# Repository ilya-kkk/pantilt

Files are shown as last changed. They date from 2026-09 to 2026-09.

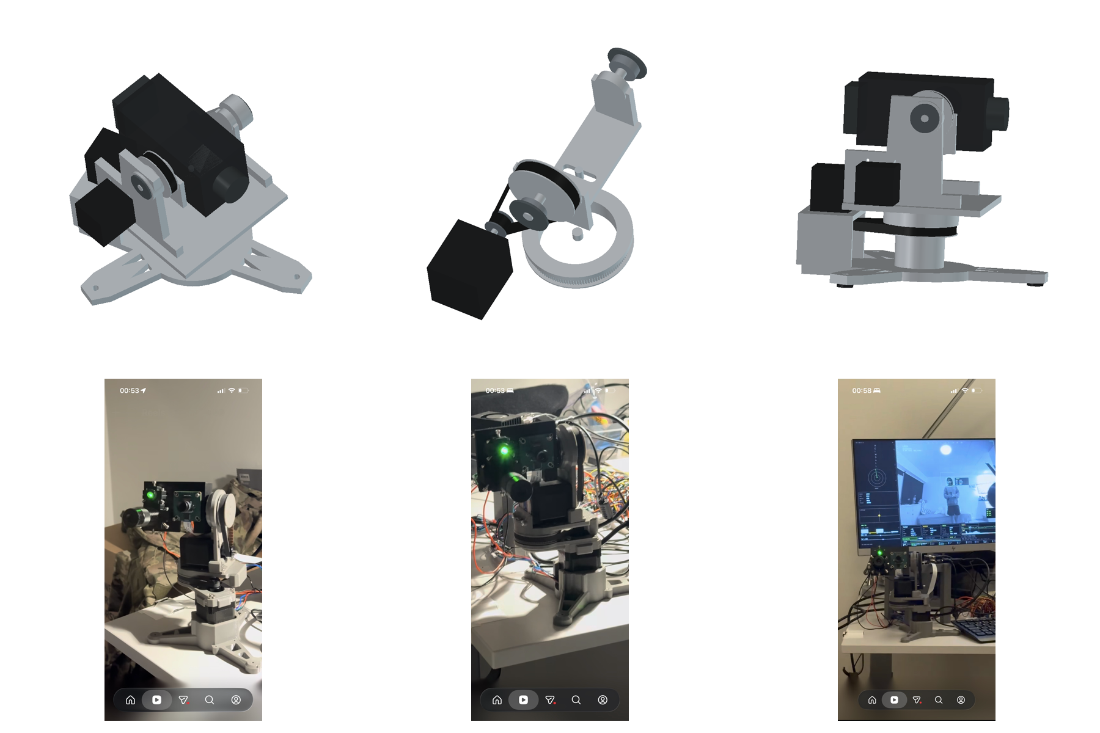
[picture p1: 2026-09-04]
screenshots/11_reference_comparison_v8.png

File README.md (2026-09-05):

# Pan/Tilt CAD Assembly V8

The printable V9 redesign is in [`v9/`](v9/): [FreeCAD assembly](v9/output/PanTilt_V9_HC-V760.FCStd), [printing and assembly guide](v9/README_RU.md), [STL parts](v9/output/stl/) and [bill of materials](v9/BOM_RU.md). V9 uses ordinary M3 screws with side-fed nuts and places the fixed pan motor below the rotating platform. The V8 reference and its history are documented below.

This workspace generates a reference-like pan/tilt concept for a Panasonic HC-V760 payload.

## Architecture

- Three-leg printed base with integral 51107 and 608 bearing seats
- Pan axial bearing: 51107/8107, 35x52x12 mm, seated 1 mm into both printed parts
- Pan radial bearing: press-fit 608-2RS in the lower base with an integral 7.9 mm plastic journal on the upper pan part
- Real GT2/2MR pan drive: downward-facing 20T motor pulley and integral printed 120T driven pulley, 10 mm face, 6:1 ratio
- Pan NEMA17 mounted above the fixed plate with its shaft pointing downward and 14 mm belt-tension travel
- One printable pan-rotating solid: 160 mm square-topped pan platform with the asymmetric two-sided yoke (rear-routed left bearing support that clears the open LCD through the tilt sweep; direct-NEMA17 right support), both gussets, plastic journal, thrust hub, skirt, and integral 120T pulley fused into a single connected solid — `PAN_ROTATING_one_piece_platform_journal_120T_GT2`
- Two shoulder-seated 608 bearings fixed in the pan yoke (the bearings and their caps stay separate insertable parts)
- One printed tilt solid combining the camera plate, both cheeks, two short 7.9 mm bearing trunnions, and the inboard 80T driven pulley
- Functional 2 mm pitch GT2/2MR modified-curvilinear profile on the integral tilt pulley: 80 teeth, 10 mm face, 50.9296 mm pitch diameter
- Explicit starting FDM fit compensation: 0.10 mm radial and 0.10 mm tangential, editable in `build_pantilt_freecad.py` and the model parameter sheet
- No shaft crosses the camera volume; each trunnion ends at its local cradle cheek
- Right-side order from camera outward: integral 80T pulley, plastic trunnion, then 608 bearing
- GT2 tilt drive inside the right yoke wall: 20T motor pulley to integral 80T cradle pulley, 4:1 ratio
- StepperOnline 17HS19-2004S1 tilt motor seated directly against the outside face of the right pan yoke
- Integrated NEMA17 interface in the yoke: 22.6 mm pilot racetrack and four M3 slots on a 31 mm square, all providing 14 mm vertical tension travel
- Stock 5x24 mm motor shaft passes through the yoke and engages the inboard 20T pulley; no extension, plate, or standoffs
- 39x98 mm camera saddle with a longitudinal 1/4-20 mounting slot
- 40 mm front overhang, 60 mm rear overhang, and 20 mm added camera-left HDMI clearance
- Tilt axis aligned to the stated COG 79.8 mm from the camera rear

## Generate

Run ./generate_pantilt_freecad.sh to regenerate the model.

Run ./open_pantilt_freecad.sh to open it.

Run /home/user/Applications/FreeCAD-1.1.3.AppImage make_screenshots_freecad.py to render the screenshot set and reference comparison sheet.

## Outputs

- pantilt_hc_v760_nema17_gt2.FCStd
- pantilt_hc_v760_nema17_gt2.step
- tilt_cradle_integral_gt2_80T.step
- tilt_cradle_integral_gt2_80T.stl
- pan_one_piece_square_platform_yokes_120T_GT2.step
- pan_one_piece_square_platform_yokes_120T_GT2.stl
- base_51107_608_downshaft_nema17.step
- base_51107_608_downshaft_nema17.stl
- geometry_validation.json
- cad_checks.md
- BOM.md
- screenshots/01_isometric_v8.png through screenshots/10_pan45_tilt18_v8.png
- screenshots/11_reference_comparison_v8.png through screenshots/19_pan_motor_shaft_down_v8.png

## Verified Concept Checks

- Every generated B-rep is valid.
- The complete printed tilt mechanism is exactly one `Part::Feature` containing exactly one connected solid.
- The complete pan rotating printed assembly — square-topped platform, both pan yokes, both gussets, plastic journal, thrust hub, connector skirt, and 120T pulley — is exactly one `Part::Feature` containing exactly one connected solid.
- The pan 120T profile contains 600 circular arcs and 120 land segments and is extruded to a 10 mm working width.
- The 51107 seat has 0.4 mm diametral clearance; the 608 pocket has 0.1 mm nominal diametral interference; the plastic journal has 0.1 mm diametral clearance in the 608 inner ring.
- The pan motor shaft points downward and its mounting face is flush with the fixed plate.
- The tilt pulley profile is one closed valid face containing 400 circular arcs and 80 land segments, extruded to a 10 mm working width.
- The integral pulley has exactly 80 grooves at 2 mm pitch; its nominal outside diameter is 50.4216 mm and its compensated outside diameter is 50.2216 mm.
- The central 60 mm span of the tilt axis contains zero cradle material and no through-shaft object exists.
- The integral 80T pulley is at least 15 mm closer to the camera centerline than the right 608 bearing center.
- The pulley maintains at least 1 mm to the right yoke and 5 mm to the camera envelope.
- The separate tilt motor plate and standoffs are absent; the motor front face has zero gap to the right yoke.
- The central pilot opening and four M3 slots are cut directly into the yoke and provide 14 mm vertical travel.
- The 22 mm motor pilot has 0.6 mm diametral clearance and the stock 24 mm shaft engages the 20T pulley envelope by 8.3 mm.
- The tilt belt, motor body, pilot, shaft, and both pulleys have zero solid interference with the right yoke.
- The pan belt has zero interference with the bearing adapter.
- The camera and cradle have zero measured interference at tilt angles -60, 0, and +60 degrees.
- The open-LCD and 20 mm HDMI service envelopes have zero interference with the cradle and left yoke at -60, 0, and +60 degrees.
- The final screenshot set was rendered at 1600x1200 and visually compared with all three supplied reference photographs.

## Production Limitations

The integral tilt pulley is now printable working geometry rather than a visual tooth placeholder. Its profile follows the GT2 construction used by the FreeCAD TimingGear macro and the Gates 2MR pitch/dimensional convention. Before committing to the full cradle print:

- print a short fit test or a reduced prototype using the actual belt and tune `gt2_radial_print_clearance` and `gt2_tangential_print_clearance` for the printer, material, nozzle, and slicer;
- print a short pan 120T tooth-sector fit test with the actual belt before committing to the full platform;
- verify the real motor pilot height, pulley hub position, connector orientation, and access for the four M3 screw heads;
- measure the actual 51107 stack, 608 bearings, and closed-loop belts;
- tune the nominal `21.9 mm` 608 press-fit pocket for the specific printer and material;
- add positive axial retention if the unit must survive transport shocks or inverted operation;
- the central cable passage is no longer available because the plastic pan journal occupies the axis;
- measure the HC-V760 with battery, open LCD, lens accessories, and connected cables;
- add exact screws, threaded inserts, bearing fits, fillets, print tolerances, and part splits;
- prototype the plastic trunnion-to-608 fit and evaluate journal wear, creep, and print-layer orientation;
- perform stiffness, vibration, motor-torque, and cable-fatigue checks.

Profile references:

- https://www.gates.com/content/dam/documents-library/catalogs/power-transmission-catalog.pdf
- https://reqrefusion.github.io/FreeCAD-Documentation-html/wiki/Macro_TimingGear.html

The accepted short-saddle v7 is preserved under `legacy_v7_short_hdmi_20260827/`. Earlier revisions remain under their corresponding legacy directories.
# pantilt

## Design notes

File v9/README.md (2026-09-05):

# PanTilt V9

See [the Russian assembly and printing guide](README_RU.md) and [bill of materials](BOM_RU.md).

V9 splits the previous monolithic parts into 21 printable parts with M3 DIN 912 screws and side-fed ordinary nuts. The fixed pan motor is now below the rotating platform. Bearings: 3×608 and 1×51107. Reductions: GT2 120:20 and 80:20, 10 mm belts.

Run `build_v9.py` with FreeCAD Python, then `inspect_v9.py`. `finish_cad.py` adds native display styling and a separate calibration coupon. See the Russian guide for fit assumptions and validation limits. This is an unprinted engineering prototype, not a physically qualified product.

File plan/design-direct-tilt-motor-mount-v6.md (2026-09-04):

---
goal: Direct Tilt Motor Mount V6
version: 6.0
date_created: 2026-08-27
last_updated: 2026-08-27
owner: Codex
status: 'Completed'
tags: [design, freecad, mechanical, nema17, belt-tension]
---

# Introduction



Remove the separate tilt motor slide plate and standoffs. Mount the selected NEMA17 directly against the outside face of the right pan yoke, with the motor pilot and four M3 fasteners sliding vertically in the yoke itself for belt tension adjustment.

## 1. Requirements & Constraints

- **REQ-001**: Use the StepperOnline 17HS19-2004S1 envelope: 42x42x48 mm body, 5x24 mm shaft, 22 mm concentric pilot, and 31 mm mounting square.
- **REQ-002**: Seat the motor front face directly against the outside surface of the right pan yoke with no spacer plate or standoffs.
- **REQ-003**: Cut a vertical racetrack opening for the 22 mm pilot with clearance over the complete tensioning travel.
- **REQ-004**: Cut four parallel vertical M3 clearance slots on the 31 mm square with the same tensioning travel.
- **REQ-005**: Keep the 20T motor pulley in the existing tilt belt plane and within the 24 mm shaft reach.
- **REQ-006**: Preserve the one-piece tilt cradle, real 80T GT2/2MR profile, bearings, no-through-shaft architecture, and camera clearances.
- **REQ-007**: Require zero volume interference between the right yoke and motor body, pilot, shaft, and pulley.
- **REQ-008**: Regenerate FCStd, STEP, standalone tilt STEP/STL, reports, v6 screenshots, and reference comparison.
- **CON-001**: Do not redesign the pan bearing or pan belt drive in this revision.
- **CON-002**: Preserve v5 under `/home/user/pantilt/legacy_v5_printable_gt2_20260827/`.
- **GUD-001**: Keep the deterministic FreeCAD 1.1.3 Python workflow.

## 2. Implementation Steps

### Implementation Phase 1

- GOAL-001: Integrate the motor interface into the pan yoke.

| Task | Description | Completed | Date |
|---|---|---|---|
| TASK-001 | Back up v5 source, CAD, print exports, reports, plan, and screenshots. | yes | 2026-08-27 |
| TASK-002 | Add the pilot diameter, height, shaft length, and tension travel as explicit parameters. | yes | 2026-08-27 |
| TASK-003 | Cut the pilot racetrack and four M3 tensioning slots into the right yoke. | yes | 2026-08-27 |
| TASK-004 | Remove the separate slide plate and four standoffs. | yes | 2026-08-27 |
| TASK-005 | Move the motor, pilot, and shaft against the yoke outer face while keeping pulley alignment. | yes | 2026-08-27 |

### Implementation Phase 2

- GOAL-002: Validate and document v6.

| Task | Description | Completed | Date |
|---|---|---|---|
| TASK-006 | Add direct-mount topology, shaft reach, and yoke-clearance checks. | yes | 2026-08-27 |
| TASK-007 | Rebuild all CAD and print artifacts and require one valid integral tilt solid. | yes | 2026-08-27 |
| TASK-008 | Require zero static and -60/0/+60 degree pose interference. | yes | 2026-08-27 |
| TASK-009 | Render and inspect v6 motor-mount, assembly, and comparison views. | yes | 2026-08-27 |
| TASK-010 | Update README, BOM, CAD checks, and mark this plan complete. | yes | 2026-08-27 |

## 3. Alternatives

- **ALT-001**: Retaining the separate slide was rejected because it adds compliance, overhang, and parts without providing a function the yoke cannot perform.
- **ALT-002**: A round stationary pilot hole was rejected because the motor pilot would block vertical belt adjustment.
- **ALT-003**: Slots only for the screws were rejected because the concentric pilot must move by the same amount as the fasteners.

## 4. Dependencies

- **DEP-001**: StepperOnline 17HS19-2004S1 product drawing and STEP model.
- **DEP-002**: `/home/user/pantilt/squashfs-root/usr/bin/freecadcmd` from FreeCAD 1.1.3.
- **DEP-003**: `/home/user/Applications/FreeCAD-1.1.3.AppImage` for screenshots.
- **DEP-004**: Local FFmpeg for the comparison sheet.

## 5. Files

- **FILE-001**: `/home/user/pantilt/build_pantilt_freecad.py` - direct mount geometry and validation.
- **FILE-002**: `/home/user/pantilt/make_screenshots_freecad.py` - v6 screenshot generation.
- **FILE-003**: `/home/user/pantilt/geometry_validation.json` - direct mount and collision checks.
- **FILE-004**: `/home/user/pantilt/pantilt_hc_v760_nema17_gt2.FCStd` - complete v6 assembly.
- **FILE-005**: `/home/user/pantilt/README.md` - architecture and production notes.
- **FILE-006**: `/home/user/pantilt/right_pan_yoke_direct_nema17.step` - standalone direct-mount yoke.
- **FILE-007**: `/home/user/pantilt/right_pan_yoke_direct_nema17.stl` - printable direct-mount yoke.

## 6. Testing

- **TEST-001**: Run `/home/user/pantilt/generate_pantilt_freecad.sh` and require exit code 0 and `VALIDATION_PASSED True`.
- **TEST-002**: Require slide and standoff feature counts to be zero and direct-mount slot count to equal five.
- **TEST-003**: Require at least 0.3 mm diametral pilot clearance and positive shaft engagement into the 20T pulley.
- **TEST-004**: Require all selected intersections, including yoke versus motor body/pilot/shaft/pulley, to be at most 0.01 mm3.
- **TEST-005**: Require valid B-reps, one integral tilt solid, and zero pose interference at -60, 0, and +60 degrees.
- **TEST-006**: Require non-empty v6 screenshots and original-resolution visual inspection of the direct mount.

## 7. Risks & Assumptions

- **RISK-001**: The remaining plastic around the lower-right motor slot must be checked after slicing for adequate perimeters and layer orientation.
- **RISK-002**: The selected motor's 24 mm shaft only provides limited pulley hub engagement after crossing the yoke wall.
- **RISK-003**: Belt tension must be set without forcing the pilot against the end of its racetrack opening.
- **ASSUMPTION-001**: The production motor is StepperOnline 17HS19-2004S1 or has an equivalent 42 mm NEMA17 face and 24 mm shaft.
- **ASSUMPTION-002**: Vertical motor travel is sufficient for assembly and tensioning of the selected closed-loop belt.

## 8. Related Specifications / Further Reading

`/home/user/pantilt/plan/design-printable-gt2-2mr-pulley-v5.md`

`https://www.omc-stepperonline.com/nema-17-bipolar-59ncm-84oz-in-2a-42x48mm-4-wires-w-1m-cable-connector-17hs19-2004s1`

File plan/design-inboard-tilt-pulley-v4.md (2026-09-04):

---
goal: Inboard Integral Tilt Pulley V4
version: 4.0
date_created: 2026-08-27
last_updated: 2026-08-27
owner: Codex
status: 'Completed'
tags: [design, architecture, freecad, mechanical, pan-tilt]
---

# Introduction



Reorder the right tilt support so the integral 80T pulley is closer to the camera than the right bearing journal. Preserve the one-piece printed tilt cradle and move only the right yoke support, bearing, motor-shaft passage, and tilt belt plane required by this order.

## 1. Requirements & Constraints

- **REQ-001**: Arrange the right tilt load path from the camera outward as cradle cheek, integral 80T pulley, plastic trunnion, and 608 bearing.
- **REQ-002**: Keep the camera plate, both cheeks, both hubs, both trunnions, and 80T pulley in exactly one `Part::Feature` containing one connected solid.
- **REQ-003**: Keep the 80T pulley center closer to camera centerline than the right 608 bearing center by at least 15 mm.
- **REQ-004**: Maintain at least 1 mm nominal lateral clearance between the 80T pulley flange and the right yoke bearing boss.
- **REQ-005**: Maintain at least 5 mm nominal lateral clearance between the camera envelope and the 80T pulley flange.
- **REQ-006**: Move the complete tilt belt path to the inboard side of the right yoke and align both pulley centers to that plane.
- **REQ-007**: Add a dedicated motor-shaft passage through the right yoke and require zero shaft-to-yoke interference.
- **REQ-008**: Preserve the left 608 support, no-through-shaft architecture, camera balance, and -60/0/+60 degree tilt range.
- **REQ-009**: Leave the pan bearing, pan drive ratio, pan motor, base, and central cable passage unchanged.
- **REQ-010**: Regenerate FCStd, STEP, validation, documentation, ten v4 views, and the comparison sheet.
- **CON-001**: Keep 10 mm nominal GT2 belt width and the existing 20T/80T tilt ratio.
- **CON-002**: Preserve v3 under `/home/user/pantilt/legacy_v3_outboard_pulley_20260827/`.
- **GUD-001**: Use the existing deterministic FreeCAD 1.1.3 Python generation workflow.

## 2. Implementation Steps

### Implementation Phase 1

- GOAL-001: Reorder the right tilt support and drive plane.

| Task | Description | Completed | Date |
|---|---|---|---|
| TASK-001 | Back up v3 source, model, STEP, reports, plan, and screenshots. | yes | 2026-08-27 |
| TASK-002 | Add explicit left/right yoke centers and move only the right yoke and 608 support outward. | yes | 2026-08-27 |
| TASK-003 | Move the integral 80T pulley to the camera side of the right bearing and shorten the bearing trunnion to start at the pulley. | yes | 2026-08-27 |
| TASK-004 | Move the motor pulley and belt plane inboard and add a right-yoke motor-shaft clearance hole. | yes | 2026-08-27 |

### Implementation Phase 2

- GOAL-002: Validate, render, and document v4.

| Task | Description | Completed | Date |
|---|---|---|---|
| TASK-005 | Add machine-readable pulley-order and lateral-clearance checks and require them for validation success. | yes | 2026-08-27 |
| TASK-006 | Regenerate FCStd and STEP and require all B-reps and the integral tilt solid to remain valid. | yes | 2026-08-27 |
| TASK-007 | Require zero selected static interference and zero pose interference at -60, 0, and +60 degrees. | yes | 2026-08-27 |
| TASK-008 | Render and inspect all v4 views, with emphasis on the right-side sequence and belt plane. | yes | 2026-08-27 |
| TASK-009 | Generate the v4 reference comparison and update README, BOM, CAD checks, and this plan. | yes | 2026-08-27 |

## 3. Alternatives

- **ALT-001**: Retaining the current right-yoke position was rejected because the 10 mm pulley and belt cannot fit between the camera cheek and bearing boss.
- **ALT-002**: Reducing the belt below 10 mm was rejected because it changes an accepted drive requirement and still leaves inadequate flange clearance.
- **ALT-003**: Moving the pulley into the camera envelope was rejected because it would violate payload clearance.

## 4. Dependencies

- **DEP-001**: `/home/user/pantilt/squashfs-root/usr/bin/freecadcmd` from FreeCAD 1.1.3.
- **DEP-002**: `/home/user/Applications/FreeCAD-1.1.3.AppImage` for screenshot generation.
- **DEP-003**: Local FFmpeg for the v4 comparison sheet.

## 5. Files

- **FILE-001**: `/home/user/pantilt/build_pantilt_freecad.py` - v4 geometry and validation generator.
- **FILE-002**: `/home/user/pantilt/make_screenshots_freecad.py` - v4 rendering and comparison generator.
- **FILE-003**: `/home/user/pantilt/README.md` - current architecture and output documentation.
- **FILE-004**: `/home/user/pantilt/BOM.md` - generated concept bill of materials.
- **FILE-005**: `/home/user/pantilt/cad_checks.md` - generated dimensional and validation report.
- **FILE-006**: `/home/user/pantilt/geometry_validation.json` - machine-readable acceptance checks.

## 6. Testing

- **TEST-001**: Run `/home/user/pantilt/generate_pantilt_freecad.sh` and require exit code 0.
- **TEST-002**: Require the 80T pulley center absolute Y coordinate to be smaller than the right bearing center absolute Y coordinate by at least 15 mm.
- **TEST-003**: Require at least 1 mm pulley-to-yoke clearance and at least 5 mm pulley-to-camera clearance.
- **TEST-004**: Require the integral tilt feature count and solid count to equal one and the through-shaft flag to remain false.
- **TEST-005**: Require every selected intersection and every -60/0/+60 degree pose intersection to be at most 0.01 mm3.
- **TEST-006**: Require ten non-empty 1600x1200 v4 screenshots and one non-empty 1800x1200 comparison sheet, followed by original-resolution visual inspection.

## 7. Risks & Assumptions

- **RISK-001**: The longer motor shaft or shaft extension needed to reach the inboard pulley requires production-level bearing and coupling selection.
- **RISK-002**: Moving only the right support makes the yoke laterally asymmetric and may require stiffness optimization after physical testing.
- **RISK-003**: Printed trunnion wear, creep, and bearing fit remain prototype-dependent.
- **ASSUMPTION-001**: “Closer to the camera” means the 80T pulley is axially inboard of the right 608 bearing, not merely visually overlapping it.
- **ASSUMPTION-002**: The current pan mechanism remains provisionally accepted and outside the scope of v4.

## 8. Related Specifications / Further Reading

`/home/user/pantilt/plan/design-integral-tilt-cradle-v3.md`

`/home/user/pantilt/legacy_v3_outboard_pulley_20260827/cad_checks.md`

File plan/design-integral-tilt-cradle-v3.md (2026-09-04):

---
goal: Integral One-Piece Tilt Cradle V3
version: 3.0
date_created: 2026-08-27
last_updated: 2026-08-27
owner: Codex
status: 'Completed'
tags: [design, architecture, freecad, mechanical, pan-tilt]
---

# Introduction



Replace the continuous tilt axle and separate driven pulley with one printed rotating tilt part. The camera cradle, both side cheeks, two short plastic trunnions, and the 80T driven pulley must form one connected solid while leaving the camera volume free of any cross-shaft.

## 1. Requirements & Constraints

- **REQ-001**: Remove the continuous steel tilt axle and every separate axle collar from the generated assembly.
- **REQ-002**: Generate exactly one printed `Part::Feature` for the camera plate, both cheeks, both bearing trunnions, hubs, and 80T driven pulley.
- **REQ-003**: Require the integral tilt feature to contain exactly one connected solid.
- **REQ-004**: Use two short 7.9 mm plastic trunnions running only from each cradle cheek into the corresponding 608 bearing.
- **REQ-005**: Keep the complete camera envelope free of a cross-shaft between the two cradle cheeks.
- **REQ-006**: Integrate the 80T pulley on the outboard side of the right trunnion and retain the existing external GT2 belt plane.
- **REQ-007**: Keep both 608 bearings seated in the existing pan yoke and leave the pan mechanism unchanged.
- **REQ-008**: Preserve the balanced camera position, mounting slot, nominal camera envelope, and -60/0/+60 degree tilt clearance.
- **REQ-009**: Regenerate FCStd, STEP, BOM, CAD checks, machine-readable validation, v3 screenshots, and a comparison sheet using all three reference photographs.
- **CON-001**: Treat plastic journal diameter, bearing fit, creep, wear, layer orientation, and exact GT2 tooth geometry as prototype-dependent production details.
- **CON-002**: Preserve v2 under `/home/user/pantilt/legacy_v2_axle_20260827/`.
- **GUD-001**: Continue using the deterministic FreeCAD 1.1.3 Python generator and existing pan architecture.

## 2. Implementation Steps

### Implementation Phase 1

- GOAL-001: Replace the tilt load path without changing pan.

| Task | Description | Completed | Date |
|---|---|---|---|
| TASK-001 | Back up the v2 generator, model, STEP, reports, and screenshots. | yes | 2026-08-27 |
| TASK-002 | Remove the separate 80T pulley, continuous steel axle, collar, plate, cheeks, and hubs. | yes | 2026-08-27 |
| TASK-003 | Fuse the plate, cheeks, solid hubs, short trunnions, 80T body, flanges, and 80 teeth into one printed feature. | yes | 2026-08-27 |
| TASK-004 | Add validation fields for one feature, one solid, and no through-shaft. | yes | 2026-08-27 |

### Implementation Phase 2

- GOAL-002: Regenerate and visually verify v3.

| Task | Description | Completed | Date |
|---|---|---|---|
| TASK-005 | Generate FCStd and STEP and require all B-reps to be valid. | yes | 2026-08-27 |
| TASK-006 | Require zero selected interference and zero pose interference at -60, 0, and +60 degrees. | yes | 2026-08-27 |
| TASK-007 | Render the ten-view v3 screenshot set and inspect the shaft-free camera volume and integral pulley. | yes | 2026-08-27 |
| TASK-008 | Generate and inspect the v3 comparison sheet against all three supplied references. | yes | 2026-08-27 |
| TASK-009 | Update README, BOM, CAD checks, and complete this plan. | yes | 2026-08-27 |

## 3. Alternatives

- **ALT-001**: A shorter separate steel shaft was rejected because the user explicitly requires the complete tilt mechanism to be one printed part.
- **ALT-002**: A separately fastened 80T pulley was rejected because it would violate the one-piece requirement and add a hub interface.
- **ALT-003**: An inboard pulley was rejected because it would consume camera clearance and diverge from the external belt architecture visible in the reference.

## 4. Dependencies

- **DEP-001**: `/home/user/pantilt/squashfs-root/usr/bin/freecadcmd` from FreeCAD 1.1.3.
- **DEP-002**: `/home/user/Applications/FreeCAD-1.1.3.AppImage` for GUI screenshot generation.
- **DEP-003**: Local FFmpeg for the reference comparison sheet.

## 5. Files

- **FILE-001**: `/home/user/pantilt/build_pantilt_freecad.py` - authoritative v3 geometry generator.
- **FILE-002**: `/home/user/pantilt/make_screenshots_freecad.py` - v3 rendering and motion-pose generator.
- **FILE-003**: `/home/user/pantilt/README.md` - architecture and production limitations.
- **FILE-004**: `/home/user/pantilt/BOM.md` - generated v3 concept bill of materials.
- **FILE-005**: `/home/user/pantilt/cad_checks.md` - generated dimensions and validation summary.
- **FILE-006**: `/home/user/pantilt/geometry_validation.json` - machine-readable v3 checks.

## 6. Testing

- **TEST-001**: Run `/home/user/pantilt/generate_pantilt_freecad.sh` and require exit code 0.
- **TEST-002**: Require `TILT_ROTATING_one_piece_cradle_trunnions_80T` to exist once and contain exactly one solid.
- **TEST-003**: Require no object label matching the removed continuous tilt axle.
- **TEST-004**: Require all generated B-reps to be valid and every selected interference volume to be at most 0.01 mm3.
- **TEST-005**: Require zero camera/cradle interference at tilt angles -60, 0, and +60 degrees.
- **TEST-006**: Require every v3 screenshot to be a non-empty 1600x1200 PNG and visually inspect the final comparison sheet.

## 7. Risks & Assumptions

- **RISK-001**: Printed trunnions running directly in 608 inner races may creep or wear and need a sacrificial sleeve or revised fit after prototyping.
- **RISK-002**: Fusing 80 visual teeth into the main body can create a heavier B-rep and remains an approximation of the GT2 profile.
- **RISK-003**: The camera placeholder omits exact battery, LCD hinge, connector, and cable geometry.
- **ASSUMPTION-001**: The integral pulley belongs outside the right bearing and remains connected through the short right trunnion, matching the visible reference belt path.
- **ASSUMPTION-002**: The existing pan assembly is accepted provisionally and must not be redesigned in this revision.

## 8. Related Specifications / Further Reading

`/home/user/pantilt/plan/design-pan-tilt-reference-v2.md`

`/home/user/pantilt/legacy_v2_axle_20260827/cad_checks.md`

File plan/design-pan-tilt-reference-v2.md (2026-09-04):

---
goal: Reference-Like Pan/Tilt Mechanical Architecture V2
version: 2.0
date_created: 2026-08-27
last_updated: 2026-08-27
owner: Codex
status: 'Completed'
tags: [design, architecture, freecad, mechanical, pan-tilt]
---

# Introduction



Replace the non-assemblable layout with a parameterized FreeCAD concept that follows the reference mechanism: a three-leg compact base, a low pan motor, a ring-supported turntable, a compact yoke, and an external tilt belt plane.

## 1. Requirements & Constraints

- **REQ-001**: Generate `/home/user/pantilt/pantilt_hc_v760_nema17_gt2.FCStd` and `/home/user/pantilt/pantilt_hc_v760_nema17_gt2.step` from `/home/user/pantilt/build_pantilt_freecad.py`.
- **REQ-002**: Use a three-leg printed base and package the pan NEMA17 below the rotating platform.
- **REQ-003**: Support pan with a purchased 110x86x12 mm turntable bearing and keep a central cable passage at least 55 mm in diameter.
- **REQ-004**: Use a 120T/20T GT2 pan reduction and an 80T/20T GT2 tilt reduction with exact visual tooth counts.
- **REQ-005**: Place the complete tilt belt path outside the right yoke wall with at least 2 mm nominal lateral clearance.
- **REQ-006**: Support tilt on two shoulder-seated 608 bearings, a continuous 8 mm steel axle, and external retaining caps/collars.
- **REQ-007**: Balance the Panasonic HC-V760 placeholder so its nominal center of gravity is within 2 mm of the tilt axis.
- **REQ-008**: Provide a longitudinal 1/4-20 camera slot and retain the 65x73x139 mm camera envelope.
- **REQ-009**: Generate normal, exploded, drive-focus, and tilt-pose screenshots plus a comparison sheet using the three supplied reference photos.
- **REQ-010**: Verify zero solid intersections for the selected belt, pulley, wall, motor, camera, and motion-pose clearance pairs.
- **CON-001**: Treat the result as a concept/fit model; exact vendor bearing geometry, GT2 tooth profile, camera ports, fasteners, and print tolerances require production detailing.
- **CON-002**: Preserve the previous generator and artifacts under `/home/user/pantilt/legacy_v1_20260827/`.
- **GUD-001**: Use the existing FreeCAD 1.1.3 AppImage runtime and Python-based deterministic generation workflow.

## 2. Implementation Steps

### Implementation Phase 1

- GOAL-001: Replace the mechanical architecture and generation code.

| Task | Description | Completed | Date |
|---|---|---|---|
| TASK-001 | Back up the v1 generator, model, STEP, reports, and screenshots to `/home/user/pantilt/legacy_v1_20260827/`. | yes | 2026-08-27 |
| TASK-002 | Rewrite `/home/user/pantilt/build_pantilt_freecad.py` with three named subassemblies: fixed base, pan rotating, and tilt rotating. | yes | 2026-08-27 |
| TASK-003 | Implement the pan turntable bearing, 120T drive ring, low motor mount, three-leg base, and cable passage. | yes | 2026-08-27 |
| TASK-004 | Implement the compact yoke, shoulder-seated 608 bearings, continuous axle, external 80T tilt drive, and balanced camera cradle. | yes | 2026-08-27 |

### Implementation Phase 2

- GOAL-002: Validate, render, and compare the v2 concept.

| Task | Description | Completed | Date |
|---|---|---|---|
| TASK-005 | Regenerate FCStd and STEP and verify all generated B-reps are valid. | yes | 2026-08-27 |
| TASK-006 | Generate `/home/user/pantilt/geometry_validation.json` and require every listed interference volume to be at most 0.01 mm3. | yes | 2026-08-27 |
| TASK-007 | Rewrite `/home/user/pantilt/make_screenshots_freecad.py` and render assembly, exploded, focus, and +/-60 degree tilt poses. | yes | 2026-08-27 |
| TASK-008 | Create `/home/user/pantilt/screenshots/11_reference_comparison.png` from the v2 render and supplied reference photographs. | yes | 2026-08-27 |
| TASK-009 | Inspect all output images at original resolution and iterate until the architecture is visually consistent with the reference. | yes | 2026-08-27 |

## 3. Alternatives

- **ALT-001**: A single 35x52x12 thrust bearing was rejected because it does not provide a complete radial and overturning-moment load path.
- **ALT-002**: Two vertically separated 608 pan bearings were rejected because they eliminate the large central cable passage and resemble the reference less closely.
- **ALT-003**: An idler-based tilt tensioner was rejected for this concept because vertical motor slots provide a simpler and fully modeled belt-tension adjustment.

## 4. Dependencies

- **DEP-001**: `/home/user/pantilt/squashfs-root/usr/bin/freecadcmd` from FreeCAD 1.1.3.
- **DEP-002**: FreeCAD GUI runtime available through `/home/user/Applications/FreeCAD-1.1.3.AppImage` for screenshot generation.
- **DEP-003**: ImageMagick or an equivalent local image compositor for the comparison sheet.

## 5. Files

- **FILE-001**: `/home/user/pantilt/build_pantilt_freecad.py` - authoritative v2 geometry generator.
- **FILE-002**: `/home/user/pantilt/make_screenshots_freecad.py` - v2 rendering and motion-pose generator.
- **FILE-003**: `/home/user/pantilt/README.md` - architecture, generation, and limitation notes.
- **FILE-004**: `/home/user/pantilt/BOM.md` - generated v2 concept bill of materials.
- **FILE-005**: `/home/user/pantilt/cad_checks.md` - generated dimensions and validation summary.
- **FILE-006**: `/home/user/pantilt/geometry_validation.json` - machine-readable geometric checks.

## 6. Testing

- **TEST-001**: Run `/home/user/pantilt/generate_pantilt_freecad.sh` and require exit code 0.
- **TEST-002**: Open the generated FCStd headlessly and require every object with a `Shape` to report `Shape.isValid() == true`.
- **TEST-003**: Require zero interference between the right yoke and each tilt belt component.
- **TEST-004**: Require zero interference between the camera/cradle and fixed pan/yoke components at tilt angles -60, 0, and +60 degrees.
- **TEST-005**: Require every screenshot to be a non-empty 1600x1200 PNG and visually inspect the final comparison sheet.

## 7. Risks & Assumptions

- **RISK-001**: The reference photographs do not reveal the internal pan bearing type or exact dimensions; the turntable bearing is an explicit engineering inference.
- **RISK-002**: The camera placeholder omits exact HC-V760 battery, display hinge, connector, and lens geometry.
- **RISK-003**: Generated pulley teeth are visual approximations and must be replaced by a vendor profile before manufacturing.
- **ASSUMPTION-001**: Conceptual resemblance means matching packaging and load-path architecture rather than reproducing undocumented dimensions.
- **ASSUMPTION-002**: A 0.6 kg payload and non-continuous pan travel are acceptable for the concept.

## 8. Related Specifications / Further Reading

`/home/user/pantilt/README.md`

`/home/user/pantilt/legacy_v1_20260827/cad_checks.md`

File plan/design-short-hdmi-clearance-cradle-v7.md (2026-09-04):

---
goal: Short HDMI Clearance Cradle V7
version: 7.0
date_created: 2026-08-27
last_updated: 2026-08-27
owner: Codex
status: 'Complete'
tags: [design, freecad, mechanical, camera, hdmi, lcd]
---

# Introduction



Replace the full-length camera platform with a short saddle centered near the measured HC-V760 center of mass. Add 20 mm of one-sided clearance on the camera-left LCD/HDMI side and widen the corresponding pan structure while preserving the accepted drive architecture.

## 1. Requirements & Constraints

- **REQ-001**: Leave the camera unsupported for 40 mm at the front and 60 mm at the rear, producing a 39 mm platform for the 139 mm camera envelope.
- **REQ-002**: Position the platform from X=-9.5 to X=29.5 mm, centered at X=10.0 mm.
- **REQ-003**: Model the camera center of mass 1.9 NEMA17 widths from the rear: X=10.3 mm, and align the tilt axis to it.
- **REQ-004**: Add 20 mm clearance only on the camera-left side for the LCD hinge and Micro HDMI cable.
- **REQ-005**: Increase the plate width from 78 to 98 mm, shifting its center 10 mm left so the opposite edge stays unchanged.
- **REQ-006**: Move the left tilt cheek, trunnion, 608 support, yoke, and pan support outward by 20 mm; leave the right drive side unchanged.
- **REQ-007**: Provide at least 20 mm between the camera-left body face and the inner face of the printed tilt cheek.
- **REQ-008**: Add explicit open-LCD and 20 mm HDMI cable clearance references and require zero solid interference with the printed cradle/yoke in the nominal pose.
- **REQ-009**: Preserve the integral GT2/2MR pulley, direct NEMA17 mount, bearing arrangement, and -60/0/+60 degree motion checks.
- **CON-001**: Camera body remains a 139x65x73 mm measured placeholder until a full physical scan is available.
- **CON-002**: Preserve v6 under `/home/user/pantilt/legacy_v6_direct_motor_20260827/`.
- **GUD-001**: Keep the deterministic FreeCAD 1.1.3 workflow.

## 2. Implementation Steps

### Implementation Phase 1

- GOAL-001: Build the short asymmetric saddle.

| Task | Description | Completed | Date |
|---|---|---|---|
| TASK-001 | Back up v6 source, CAD, exports, reports, plan, and screenshots. | yes | 2026-08-27 |
| TASK-002 | Parameterize front/rear overhang, platform length/center, COG, and left cable allowance. | yes | 2026-08-27 |
| TASK-003 | Shorten the platform and side cheeks around the new tilt axis. | yes | 2026-08-27 |
| TASK-004 | Shift only the left cheek/trunnion/bearing/yoke outward by 20 mm. | yes | 2026-08-27 |
| TASK-005 | Widen the pan platform support to carry the asymmetric yoke span. | yes | 2026-08-27 |

### Implementation Phase 2

- GOAL-002: Validate operational clearances.

| Task | Description | Completed | Date |
|---|---|---|---|
| TASK-006 | Add open-LCD and HDMI cable envelope objects and nominal collision checks. | yes | 2026-08-27 |
| TASK-007 | Add exact front/rear overhang, COG alignment, and side-clearance validation. | yes | 2026-08-27 |
| TASK-008 | Rebuild FCStd, STEP, standalone printable exports, and reports. | yes | 2026-08-27 |
| TASK-009 | Render and inspect v7 platform, HDMI/LCD, assembly, and comparison views. | yes | 2026-08-27 |
| TASK-010 | Update README, BOM, CAD checks, and mark this plan complete. | yes | 2026-08-27 |

## 3. Alternatives

- **ALT-001**: Symmetric widening was rejected because it would provide only 10 mm on the side that needs a 20 mm cable allowance.
- **ALT-002**: Keeping the 160 mm plate was rejected because the requested front and rear camera overhangs intentionally eliminate unnecessary plastic.
- **ALT-003**: Leaving the tilt axis at the geometric camera center was rejected because the supplied center-of-mass estimate places it 10.3 mm forward of camera center.

## 4. Dependencies

- **DEP-001**: Panasonic HC-V760 operating instructions for LCD and Micro HDMI component placement.
- **DEP-002**: `/home/user/pantilt/squashfs-root/usr/bin/freecadcmd` from FreeCAD 1.1.3.
- **DEP-003**: `/home/user/Applications/FreeCAD-1.1.3.AppImage` for screenshots.
- **DEP-004**: Local FFmpeg for the reference comparison.

## 5. Files

- **FILE-001**: `/home/user/pantilt/build_pantilt_freecad.py` - v7 geometry and checks.
- **FILE-002**: `/home/user/pantilt/make_screenshots_freecad.py` - v7 render set.
- **FILE-003**: `/home/user/pantilt/geometry_validation.json` - machine-readable acceptance results.
- **FILE-004**: `/home/user/pantilt/pantilt_hc_v760_nema17_gt2.FCStd` - complete assembly.
- **FILE-005**: `/home/user/pantilt/tilt_cradle_integral_gt2_80T.stl` - revised short saddle.
- **FILE-006**: `/home/user/pantilt/left_pan_yoke_lcd_clearance.stl` - rear-routed LCD-clearance support.
- **FILE-007**: `/home/user/pantilt/pan_platform_wide_150mm.stl` - widened pan platform.

## 6. Testing

- **TEST-001**: Require generated front and rear overhangs to equal 40 and 60 mm within 0.01 mm.
- **TEST-002**: Require tilt-axis-to-estimated-COG X error to be at most 0.01 mm.
- **TEST-003**: Require at least 20 mm camera-to-left-cheek clearance and unchanged right-side pulley/yoke clearances.
- **TEST-004**: Require zero nominal solid intersection with the LCD and HDMI clearance envelopes.
- **TEST-005**: Require valid B-reps, one integral tilt solid, and zero selected pose interference at -60, 0, and +60 degrees.
- **TEST-006**: Require non-empty v7 screenshots and original-resolution inspection of the short platform and left-side clearance.

## 7. Risks & Assumptions

- **RISK-001**: The LCD and connector envelopes are conservative placeholders; exact hinge and cable geometry still require physical measurement.
- **RISK-002**: A 39 mm saddle concentrates camera mounting loads and needs adequate wall thickness, infill, and a washer/insert around the 1/4-20 slot.
- **RISK-003**: The wider asymmetric yoke increases pan inertia and overhang on the left side.
- **ASSUMPTION-001**: Camera forward is +X and camera-left is +Y.
- **ASSUMPTION-002**: The 20 mm requirement is clear distance from the camera body to the nearest printed cheek, not total assembly widening.

## 8. Related Specifications / Further Reading

`/home/user/pantilt/plan/design-direct-tilt-motor-mount-v6.md`

`https://www.panasonic.com/content/dam/Panasonic/support_manual/camcorders/english/HC-VX870M_Operating_Instructions.pdf`

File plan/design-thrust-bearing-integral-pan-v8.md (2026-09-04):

---
goal: Thrust Bearing Integral Pan V8
version: 8.0
date_created: 2026-08-28
last_updated: 2026-08-28
owner: Codex
status: Complete
tags: [freecad, mechanical, pan, gt2, bearing]
---

# Thrust Bearing Integral Pan V8

Replace the 110 mm turntable bearing and conceptual pan teeth with a low stack using a 51107 thrust bearing, a lower 608 radial bearing, an integral printed journal, and a real 120T GT2/2MR pulley.

## Requirements

- Seat a 51107/8107 35x52x12 mm bearing between 1 mm locating recesses in the fixed base and rotating pan platform.
- Press a 608-2RS into the fixed base and locate it with a 7.9 mm plastic journal integral to the rotating pan part.
- Combine the pan platform, thrust hub, journal, connector skirt, and 120T pulley into one printable solid.
- Use a production-profile 120T GT2/2MR pulley with a 10 mm face.
- Mount the pan NEMA17 above the fixed plate with its shaft pointing downward and retain 14 mm tension adjustment.
- Preserve all accepted v7 tilt, LCD, HDMI, and camera-saddle geometry.

## Verified Results

- 51107 seat: 52.4 mm diameter, 1.0 mm depth each side, 0.4 mm diametral clearance.
- Pan 608 pocket: 21.9 mm nominal diameter, 0.1 mm nominal diametral interference.
- Integral journal: 7.9 mm diameter, 0.1 mm diametral clearance to the 608 bore.
- Pan GT2 profile: 120 teeth, 600 arcs, 120 land segments, closed valid profile, 10 mm face.
- Pan and tilt printed mechanisms each contain one connected solid.
- Selected static and -60/0/+60 degree interference checks are zero.

## Production Notes

- Confirm press fits with small calibration coupons before printing full parts.
- Confirm the actual closed-loop pan belt after choosing the final motor position; 350 mm is the current estimate.
- Add positive axial retention for transport or inverted use.
- The integral central journal removes the previous central cable passage.

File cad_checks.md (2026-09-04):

# CAD Checks V8

## Architecture
- Three-leg base with the pan motor mounted above its fixed plate and the shaft pointing downward.
- Pan axial load path uses a 51107 / 8107 35x52x12 mm thrust bearing in two 1 mm locating seats.
- Pan radial location uses a press-fit 608 in the lower base and a 7.9 mm plastic journal integral to the pan platform.
- The square (152 mm) topped pan platform, both pan yokes, both gussets, journal, thrust hub, connector skirt, and real 120T GT2/2MR pulley form one printed solid.
- The pan platform top face is a square plate, not a disc; both yoke footprints (left yoke y=66..76, right yoke y=-66.5..-56.5, both x=-76..52) sit fully inside it, with both gussets integral.
- Tilt rotating structure is one printed solid: plate, cheeks, hubs, two short 7.9 mm trunnions, and integral 80T pulley.
- Right-side order from camera outward is 80T pulley, plastic bearing trunnion, and 608 bearing.
- There is no shaft or printed material crossing the camera volume along the central tilt-axis span.
- Two shoulder-seated 608 bearings remain fixed in the pan yoke.
- Tilt belt plane is inboard of the right yoke wall at Y=-45.8 mm.
- Tilt motor front face seats directly against the right yoke; there is no separate slide plate or standoff.
- The right yoke contains one vertical pilot racetrack and four M3 tensioning slots over 14.0 mm travel.
- Camera saddle is 39.0x98.0 mm, leaving 40.0 mm front and 60.0 mm rear overhang.
- Tilt axis X=10.3 mm follows the stated camera COG at 79.8 mm from the rear.
- Camera-left clearance to the rotating cheek is 21.5 mm; the left fixed support is routed behind the LCD sweep.

## Drive
- Pan pitch diameter: 76.39 mm, ratio 6.0:1.
- Pan profile topology: 600 arcs, 120 land segments, closed=True.
- Pan compensated outside diameter: 75.6864 mm with a 10.0 mm face.
- Tilt pitch diameter: 50.93 mm, ratio 4.0:1.
- Integral tilt pulley uses a closed GT2/2MR modified-curvilinear outline with 80 teeth and a 10.0 mm face.
- Tilt profile topology: 400 arcs, 80 land segments, closed=True.
- Tilt pitch diameter: 50.9296 mm.
- Nominal 2MR outside diameter: 50.4216 mm.
- Compensated outside diameter: 50.2216 mm.
- Starting FDM compensation: 0.10 mm radial and 0.10 mm tangential.
- The pan 120T pulley uses the same closed GT2/2MR modified-curvilinear construction as the production tilt pulley.
- Selected tilt motor: StepperOnline 17HS19-2004S1, pilot 22.0x2.0 mm, mounting square 31.0 mm.
- Pilot diametral slot clearance: 0.60 mm.
- Motor-face gap to yoke: 0.000 mm.
- Shaft engagement into the 20T pulley envelope: 8.30 mm.

## Balance
- Nominal camera COG offset from the tilt axis: 1.00 mm.
- Nominal camera-only gravity torque: 0.0059 N m.

## Interference checks
- tilt_right_yoke_vs_motor_body: 0.000000 mm3
- tilt_right_yoke_vs_motor_pilot: 0.000000 mm3
- tilt_right_yoke_vs_motor_pulley: 0.000000 mm3
- tilt_right_yoke_vs_motor_shaft: 0.000000 mm3
- tilt_right_yoke_vs_integral_cradle: 0.000000 mm3
- tilt_right_608_vs_integral_cradle: 0.000000 mm3
- tilt_left_608_vs_integral_cradle: 0.000000 mm3
- tilt_right_yoke_vs_belt: 0.000000 mm3
- pan_base_vs_motor_body: 0.000000 mm3
- pan_base_vs_motor_pilot: 0.000000 mm3
- pan_base_vs_motor_shaft: 0.000000 mm3
- pan_base_vs_motor_pulley: 0.000000 mm3
- pan_base_vs_belt: 0.000000 mm3
- pan_base_vs_integral_pan: 0.000000 mm3
- pan_motor_vs_integral_pan: 0.000000 mm3
- pan_608_vs_integral_journal: 0.000000 mm3
- pan_51107_lower_vs_integral_pan: 0.000000 mm3
- pan_51107_upper_vs_integral_pan: 0.000000 mm3
- camera_vs_tilt_motor_nominal: 0.000000 mm3
- integral_cradle_vs_tilt_motor_nominal: 0.000000 mm3
- open_lcd_vs_integral_cradle: 0.000000 mm3
- open_lcd_vs_left_yoke: 0.000000 mm3
- hdmi_clearance_vs_integral_cradle: 0.000000 mm3
- hdmi_clearance_vs_left_yoke: 0.000000 mm3

## Tilt pose checks
- Tilt -60 deg: 0.000000 mm3
- Tilt 0 deg: 0.000000 mm3
- Tilt 60 deg: 0.000000 mm3

## Result
- Valid B-reps: True
- Integral tilt Part::Feature count: 1
- Integral tilt solid count: 1
- Integral pan Part::Feature count: 1
- Integral pan solid count: 1
- 51107 seat clearance: 0.40 mm diametral
- Pan 608 pocket interference: 0.10 mm diametral
- Plastic journal-to-608 clearance: 0.10 mm diametral
- Pan motor shaft points down: True
- Through tilt shaft present: False
- Central cross-shaft material: 0.000000 mm3
- Pulley closer to camera than right bearing: True
- Pulley-to-bearing center margin: 20.20 mm
- Pulley-to-right-yoke clearance: 1.60 mm
- Pulley-to-camera clearance: 7.20 mm
- Direct-mount slot count: 5
- Separate slide/standoff features: 0
- Geometry validation passed: True

## Production limitations
- Print and test the 2MR profile against the actual 10 mm belt, then tune the two explicit compensation parameters for the printer, material, nozzle, and slicer.
- Prototype the printed trunnion fit and check wear, creep, and layer orientation at both 608 bearings.
- Verify the actual 17HS19-2004S1 pilot height, shaft tolerances, pulley hub position, and connector clearance before printing the final yoke.
- Confirm the physical 51107 stack height, 608 fit, and closed-loop belt length before final printing.
- The central cable passage is intentionally removed because the integral plastic pan journal occupies the rotation axis; route cables outside the axis or add a later slip-ring solution.
- Add positive axial retention for transport or inverted operation; the present 51107 stack is retained downward by payload gravity.
- Measure the physical HC-V760 including battery, LCD travel, lens, and connectors.
- Verify the modeled LCD hinge X=35.0 mm and the HDMI plug envelope against the physical camera before final printing.
- Add final screw threads, inserts, tolerances, fillets, and print-orientation details.

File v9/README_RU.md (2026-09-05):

# PanTilt V9 для Panasonic HC-V760

Разборная конструкция для двух NEMA17, ремней GT2 шириной 10 мм, трёх 608 и упорного 51107. Крепёж печатных деталей — обычные M3 DIN 912 и гайки M3 с загрузкой сбоку. Вплавляемых вставок нет.

В архиве откройте `output/PanTilt_V9_HC-V760.FCStd`. Разверните `Assembly`: `Fixed` — основание, `Pan` — поворотная часть, `Tilt` — камера с люлькой. Выберите `Pan` и изменяйте `PanAngle`; у `Tilt` меняйте `TiltAngle`. Для осмотра внутренних деталей скройте `Camera HC V760 envelope` клавишей пробела. Голубые габариты открытого экрана и HDMI по умолчанию скрыты. При необходимости нажмите V, F для вписывания всей сборки в экран.

Это нативный документ FreeCAD с отдельными твердотельными деталями и управляемыми углами. Геометрические размеры меняются в генераторе и `fit_parameters.json`, затем модель пересоздаётся. Таблица `Parameters` справочная; это не дерево эскизов с полной параметризацией всех деталей. Проверено в FreeCAD 1.1.3.

## Что изменилось относительно V8

- Двигатель pan перенесён под платформу, вал направлен вверх. У V8 при повороте квадратная платформа заходила в габарит неподвижного мотора. В V9 весь неподвижный привод расположен ниже вращающейся платформы.
- Монолит разделён на 21 печатную деталь. Стойки, площадки, щеки и крышки печатаются отдельно; в соединениях используются позиционирующие выступы и боковые карманы гаек.
- Отверстия M3 имеют диаметр 3,5 мм; обычные цилиндрические головки утоплены там, где это допускает толщина. Основные наружные углы скруглены; у основания колонны радиус 6 мм.
- Сохранены реальные профили больших шкивов GT2/2MR: 120 зубьев pan и 80 зубьев tilt. Передаточные отношения 6:1 и 4:1 при малых шкивах 20T.
- Подшипники фиксируются крышками. Посадка наружного кольца рассчитана на установку без запрессовки; несущие поверхности не зажимают одновременно внутреннее и наружное кольца.
- В обеих осях предусмотрено 14 мм перемещения мотора для монтажа и натяжения ремня. В модели мотор стоит в расчётном положении; перемещение мотора не связано отдельным ограничением сборки.

## Файлы

| Путь | Назначение |
|---|---|
| `output/PanTilt_V9_HC-V760.FCStd` | Цветная сборка FreeCAD с подшипниками, крепежом и габаритом камеры |
| `output/PanTilt_V9_assembly.step` | Сборка в нейтральном формате |
| `output/stl/` | 21 деталь и один калибровочный образец; каждая деталь уже ориентирована для печати и поставлена на Z=0 |
| `output/step/` | Отдельные детали; основные детали сохранены в координатах сборки |
| `output/views/` | Виды с двух сторон, без камеры, при наклоне и разнесённый обзор |
| `output/geometry_validation.json` | Результаты независимой проверки сохранённой модели |
| `output/hardware.json`, `BOM_RU.md` | Крепёж с длинами и перечень покупных деталей |
| `build_v9.py`, `fit_parameters.json` | Воспроизводимый генератор и посадочные размеры |

Разнесённый вид иллюстрирует состав конструкции; он не заменяет приведённую ниже последовательность сборки. Модели камеры, моторов, малых шкивов и подшипников упрощены. Изображения получены из геометрии CAD, не сгенерированы по текстовому описанию.

## Сначала маленький образец

Напечатайте `CAL_Fit_coupon.stl` тем же материалом, слоем и настройками, что будут у механизма. Он проверяет реальные размеры вашего принтера, включая усадку и погрешность отверстий. Усадка не заменена масштабированием всего изделия: зазоры заданы в ответственных сопряжениях.

Положите образец стойками вверх, двумя маленькими метками слева. Слева направо:

| Элементы образца | Номинальные размеры модели, мм |
|---|---|
| Три больших отверстия | 22,1 / 22,3 / 22,5 под наружное кольцо 608 |
| Три малых отверстия у переднего края | 3,3 / 3,5 / 3,7 под M3 |
| Три боковых кармана справа спереди | Ширина 5,7 / 5,9 / 6,1; высота 2,8 |
| Три стойки с осевым отверстием | Наружный диаметр 7,8 / 7,9 / 8,0 под внутреннее кольцо 608 |

Выберите посадку наружного кольца, при которой оно входит пальцами и не болтается; крышка удержит его от выпадения. Для цапфы нужна плотная ручная посадка без заметного радиального люфта: внутреннее кольцо должно вращаться вместе с цапфой. Не забивайте подшипник молотком. Если 7,8 мм у вашего принтера получается свободно, увеличьте `journal_d` по результату образца и пересоздайте детали.

Гайка должна входить сбоку, удерживаться от проворота и совмещаться с отверстием. Значения по умолчанию: отверстие 3,5; карман гайки 5,9×2,8; головка 6,2×3,3; посадка 608 — 22,3; цапфа — 7,8. Посадочные диаметры и ширину кармана можно поправить в JSON. Глубина циковки связана с длинами болтов и толщиной стенок: не меняйте её без проверки этих связей.

## Печать

Для первого функционального экземпляра предлагается PETG, слой 0,16–0,20 мм, сопло 0,4 мм, 5–6 периметров и 40–50% заполнения. Это стартовые настройки, а не испытанный профиль под конкретный принтер. Для цапф, крышек и зон гаек используйте плотное заполнение; тонкая цапфа с шестью стенками практически заполняется целиком. На зубчатых профилях не размещайте шов на рабочей боковой поверхности зуба.

| Детали | Ориентация STL | Где проверить поддержки |
|---|---|---|
| B01 — колонна основания | Основанием вниз | Локальные мосты боковых карманов гаек |
| B02 — три ноги; B03 — опора мотора | Плоской стороной вниз | Небольшие мосты карманов гаек |
| B04 — две стенки опоры мотора | Широкой плоскостью на стол | Боковые отверстия M3 и карманы; внешние поддержки обычно не нужны |
| B05 — верхняя площадка мотора | Плоскостью вниз | Просмотреть мосты и циковки в слайсере |
| B06 — крышка нижнего 608 | Верхней стороной вниз | Небольшие мосты над отверстиями |
| P01 — ротор 120T | Верхней плоскостью на стол, цапфой вверх | Зубья и юбка растут от плоского основания; карманы гаек имеют короткие мосты |
| P03 — поворотная платформа | Нижней плоскостью вниз | Циковки на нижней стороне перекрываются короткими мостами |
| P04 — две стойки | Наружной плоской стороной на стол | Отверстия крепления подошвы печатаются горизонтально; проверьте их верхние участки |
| T01 — площадка камеры | Нижней плоскостью вниз | Короткие мосты циковок |
| T02 — обе щеки, включая 80T | Плоскостью со стороны камеры на стол, цапфой вверх | Под шкивом сделана сплошная опора; проверьте боковые каналы гаек |
| Крышки и осевые шайбы | Плашмя | Обычно не требуют внешних поддержек |

STL уже повёрнуты указанным образом. Не запускайте автоматическую ориентацию всех деталей без просмотра результата. Конструкция рассчитана на короткие мосты и минимум поддержек, но проверка реальным слайсером и печать ещё не выполнялись. Уберите «слоновью ногу» у шпонок и посадок; не добавляйте одновременно большой компенсационный масштаб в слайсере и в модели.

## Порядок сборки

1. **Подготовьте гайки.** Вставьте M3 в боковые каналы деталей до закрытия соседними деталями. Для позиционирования используйте временно вкрученный длинный M3. Каналы прямоугольные, гайка лежит поперёк оси болта.
2. **Основание.** Вставьте гайки в три ноги B02 и опору мотора B03. Заведите тонкие выступы в вырезы B01; соедините восемью M3×10 сверху. Ноги можно закрепить на столе через длинные пазы; крепёж к столу подбирается отдельно.
3. **Опора pan-мотора.** Прикрепите две стенки B04 к B03 четырьмя M3×16 снизу. Установите мотор под B05 валом вверх и закрепите четырьмя M3×6. Головки находятся в длинных циковках сверху; пока не затягивайте их окончательно. Прикрепите B05 к стенкам четырьмя M3×12 сверху. Мотор должен свободно сдвигаться вдоль пазов.
4. **Подшипники pan.** Установите 608 в B01 и закройте B06 тремя M3×10. Вложите нижнюю шайбу 51107, сепаратор с шариками и верхнюю шайбу в правильном порядке согласно вашему подшипнику. Посадочная шайба с меньшим отверстием относится к вращающемуся узлу. Модель шариков — только габарит, для печати она не предназначена.
5. **Ротор pan.** Заранее установите центральную гайку и четыре периферийные гайки в P01. Наденьте ремень 350 мм на большой шкив и опустите ротор на подшипники. Снизу установите P02 и M3×20. Затягивайте только до устранения лишнего осевого хода: вращение должно оставаться свободным. Соедините платформу P03 с ротором четырьмя M3×10 сверху.
6. **Ремень pan.** Установите покупной 20T на вал, ступицей к мотору. Совместите середины рабочих дорожек большого и малого шкивов (в модели Z=75 мм). Наденьте ремень, отведите мотор по пазам до устранения провисания и затяните его четыре болта. Не натягивайте ремень как струну. Винты ступицы малого шкива — штатные, поставляются с ним.
7. **Люлька.** Вставьте боковые и осевые гайки в обе T02. Соедините щеки с T01 четырьмя M3×16 снизу; выступы входят в карманы площадки. Большой 80T находится справа от камеры. До установки внешней правой стойки наденьте на него ремень 280 мм.
8. **Стойки tilt.** Вставьте гайки крышек и подошв в P04. Прикрепите tilt-мотор к правой стойке четырьмя M3×12 с внутренней стороны, оставив возможность двигать его. На цапфы люльки наденьте 608, затем подведите стойки снаружи; подшипники входят в наружные посадки. Поставьте стойки выступами в платформу и закрепите шестью M3×16 снизу. Установка люльки между уже жёстко закреплёнными стойками не предусмотрена.
9. **Фиксация tilt.** Установите две P05 по три M3×10 на каждую. Снаружи цапф поставьте T03: слева осевой M3×25, справа M3×35. Проверьте свободное вращение до установки ремня на малый шкив. Крышка удерживает наружное кольцо 608; осевая шайба не должна тереться об неё.
10. **Ремень tilt.** Установите второй 20T ступицей к мотору. Совместите рабочие дорожки по Y=−45,8 мм, наденьте ремень и отрегулируйте натяжение горизонтальным перемещением мотора. После этого затяните крепление двигателя. Прокрутите вручную весь рабочий диапазон.
11. **Камера.** Закрепите её штатным винтом **1/4–20**, не M3. Толщина площадки 8 мм. Подберите длину по фактическому выступанию резьбы над площадкой и допустимой глубине гнезда камеры; шайбы можно использовать для ограничения выступа. Не затягивайте винт, если он упёрся в дно гнезда. Камеру можно сдвинуть вдоль продольного паза для балансировки. При необходимости положите тонкую нескользящую прокладку и заново проверьте высоту и длину винта.
12. **Проводка.** Выведите провода tilt-мотора и HDMI с запасом на движение, закрепите их на стойке, затем на неподвижной части. Геометрические 360° pan не означают бесконечного вращения с обычными проводами: установите программные пределы по реальной проводке. Первая проверка движения — без камеры, затем с эквивалентным грузом над мягкой поверхностью.

## Проверено и что остаётся измерить

Независимый скрипт открывает уже сохранённый FCStd, проверяет валидность 21 печатного тела, отсутствие их взаимных объёмных пересечений, пересечений с болтами/гайками и основными покупными компонентами. Наклон проверен от −60° до +60° через 3°, pan — 0…350° через 10°. Свойства углов проверены изменением на 30° и возвратом в ноль. Порог сообщения об объёмном пересечении — 0,015 мм³. Проверки дискретные, отдельно для каждой оси; они не являются непрерывным доказательством отсутствия коллизий во всех сочетаниях углов.

Ремни показаны номинальными габаритами, без сопряжения каждого зуба; проверка контакта зубьев и расчёт натяжения под нагрузкой не выполнялись. Посадки, жёсткость, нагрев пластика рядом с моторами и ресурс требуют проверки физического образца. Значение удерживающего момента мотора не является допустимой нагрузкой всей печатной конструкции.

Размеры корпуса камеры 139×65×73 мм, расположение оси по X=10,3 мм, экран и HDMI перенесены из исходного проекта. Это габаритные допущения, не обмер именно вашей камеры. Перед печатью крупных деталей сверить положение штативного гнезда, фактический центр тяжести с батареей, выступы объектива, ход экрана и разъём с подключённым кабелем. Седло короткое (39 мм вдоль камеры), как в предыдущей версии проекта. У покупных 20T проверить ширину дорожки не менее 10 мм, диаметр ступицы и расположение стопорного винта.

Параметры мотора 42×42×48 мм и вал 5×24 мм соответствуют [StepperOnline 17HS19-2004S1](https://www.omc-stepperonline.com/nema-17-bipolar-59ncm-84oz-in-2a-42x48mm-4-wires-w-1m-cable-connector-17hs19-2004s1). Руководство камеры доступно на [официальной странице Panasonic](https://eww.pavc.panasonic.co.jp/hdw/oi/WX970/), раздел CIS / HC-V760.

## Воспроизведение и перенос в репозиторий

Поместите папку `v9` рядом с исходным `build_pantilt_freecad.py` из main. В комплекте `source/build_pantilt_freecad.py` — неизменённый необходимый модуль V8. Генератор использует его GT2-профиль, но не запускает сборку V8.

В Python Console FreeCAD можно выполнить, подставив путь к вашей папке:

```python
exec(compile(open('/path/to/pantilt/v9/build_v9.py', encoding='utf-8').read(), '/path/to/pantilt/v9/build_v9.py', 'exec'), {'__file__':'/path/to/pantilt/v9/build_v9.py', '__name__':'__main__'})
```

Для пакетного запуска используйте Python, в котором доступны модули FreeCAD, Part и MeshPart. Последовательность: `build_v9.py`, `inspect_v9.py`, `finish_cad.py`, `export_step.py`. `finish_cad.py` оформляет отображение и добавляет калибровочный STL; требует GUI-модуля. `export_step.py` экспортирует мировые координаты и проверяет габариты STEP после открытия. `render_views.py` — отдельный необязательный CPU-рендер, ему нужны Python, NumPy, Pillow и g++.

Исходники, инструкция и готовые CAD/STL/STEP находятся в папке `v9/` ветки `codex/pantilt-v9-printable-m3`. В ранее переданном архиве также есть `pantilt-v9.patch` с исходниками и инструкцией; для переноса в чистую копию исходной версии применить из корня репозитория: `git apply /path/to/pantilt-v9.patch`. При работе с этой веткой применять патч повторно не требуется.

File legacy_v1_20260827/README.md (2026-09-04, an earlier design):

# Pan/Tilt CAD Assembly

This workspace generates a FreeCAD assembly for a Panasonic HC-V760 pan/tilt camera mechanism:

- Panasonic HC-V760 camera envelope: `65 x 73 x 139 mm`
- Two NEMA17 motors
- GT2-10 belt drives on pan and tilt
- Bearing-supported rotating axes: pan stack plus 608-style tilt shaft bearings
- Editable dimensions in `build_pantilt_freecad.py`

Generate with:

```bash
./generate_pantilt_freecad.sh
```

Open in FreeCAD:

```bash
./open_pantilt_freecad.sh
```

Expected outputs:

- `pantilt_hc_v760_nema17_gt2.FCStd`
- `pantilt_hc_v760_nema17_gt2.step`

The model is a layout/fit assembly, not a finalized printable part set. Measure the real camera with battery, lens cap, screen clearance, and cable exits before manufacturing.

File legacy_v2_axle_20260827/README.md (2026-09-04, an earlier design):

# Pan/Tilt CAD Assembly V2

This workspace generates a reference-like pan/tilt concept for a Panasonic HC-V760 payload.

## Architecture

- Three-leg printed base with the pan NEMA17 packaged below the turntable
- Sealed 110x86x12 mm pan turntable bearing with a 55 mm cable passage
- GT2 pan drive: 20T motor pulley and 120T driven ring, 6:1 ratio
- Compact two-sided yoke with local gussets and bearing bosses
- Two shoulder-seated 608 bearings and one continuous 8 mm steel tilt axle
- GT2 tilt drive fully outside the right yoke wall: 20T to 80T, 4:1 ratio
- External tilt motor slide with vertical belt-tension adjustment
- 160x78 mm camera plate with a longitudinal 1/4-20 mounting slot
- Nominal camera center of gravity within 1 mm of the tilt axis

## Generate

Run ./generate_pantilt_freecad.sh to regenerate the model.

Run ./open_pantilt_freecad.sh to open it.

Run /home/user/Applications/FreeCAD-1.1.3.AppImage make_screenshots_freecad.py to render the screenshot set.

## Outputs

- pantilt_hc_v760_nema17_gt2.FCStd
- pantilt_hc_v760_nema17_gt2.step
- geometry_validation.json
- cad_checks.md
- BOM.md
- screenshots/01_isometric_v2.png through screenshots/10_pan45_tilt18_v2.png
- screenshots/11_reference_comparison.png

## Verified Concept Checks

- Every generated B-rep is valid.
- The tilt belt, both pulleys, motor slide, and standoffs have zero solid interference with the right yoke.
- The pan belt has zero interference with the bearing adapter.
- The camera and cradle have zero measured interference at tilt angles -60, 0, and +60 degrees.
- The final screenshot set was rendered at 1600x1200 and visually compared with all three supplied reference photographs.

## Production Limitations

This is a mechanically coherent concept/fit model, not a print-ready release. Before manufacturing:

- replace visual GT2 teeth with exact vendor profiles;
- select and measure the actual turntable bearing and closed-loop belts;
- measure the HC-V760 with battery, open LCD, lens accessories, and connected cables;
- add exact screws, threaded inserts, bearing fits, fillets, print tolerances, and part splits;
- perform stiffness, vibration, motor-torque, and cable-fatigue checks.

The previous layout and screenshots are preserved under legacy_v1_20260827/.

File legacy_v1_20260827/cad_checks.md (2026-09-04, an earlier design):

# CAD Checks

## Load path
- Pan load path: camera -> tilt cradle -> tilt supports -> rotating upper plate -> pan hub bearings -> base.
- Tilt load path: camera -> camera plate -> 8 mm tilt axle -> two 608 bearings -> yoke supports.
- NEMA17 shafts are motor-input shafts only and do not support camera mass.

## Parameters
- Pan driven pitch diameter: 50.93 mm from 80T GT2.
- Tilt driven pitch diameter: 50.93 mm from 80T GT2.
- Bearing pocket clearance parameter: 0.15 mm.
- Tilt axis height above camera plate: 40.0 mm.

## Motion checks
- Pan check poses represented by reference axis: -90, 0, +90 deg. Center bearing stack is axisymmetric; motor is offset and belt plane clears top platform in nominal CAD.
- Tilt check poses considered by camera envelope and 95 mm inner yoke width: -60, 0, +60 deg are intended. Final collision must be rechecked after exact battery/cable geometry.

## Center of gravity
- CAMERA_COG is shown near the camera envelope center. Initial offset from TiltAxis is about dx=16.0 mm, dz=1.0 mm.
- Reduce this offset by sliding the camera in the 1/4-20 longitudinal slot and adjusting TILT_AXIS_HEIGHT_ABOVE_PLATE.

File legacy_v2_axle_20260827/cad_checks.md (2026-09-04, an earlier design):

# CAD Checks V2

## Architecture
- Three-leg reference-like base with the pan motor below the turntable.
- Pan load path uses a 110x86x12 mm turntable bearing.
- Tilt load path uses a continuous 8 mm steel axle and two shoulder-seated 608 bearings.
- Tilt belt plane is fully outside the right yoke wall.
- Central pan cable passage is 55.0 mm.

## Drive
- Pan pitch diameter: 76.39 mm, ratio 6.0:1.
- Tilt pitch diameter: 50.93 mm, ratio 4.0:1.
- Visual pulley geometry contains exactly 120 pan teeth and 80 tilt teeth.
- Motor slots follow each belt tension direction.

## Balance
- Nominal camera COG offset from the tilt axis: 1.00 mm.
- Nominal camera-only gravity torque: 0.0059 N m.

## Interference checks
- tilt_right_yoke_vs_motor_pulley: 0.000000 mm3
- tilt_right_yoke_vs_driven_pulley: 0.000000 mm3
- tilt_right_yoke_vs_belt: 0.000000 mm3
- tilt_standoffs_vs_belt: 0.000000 mm3
- tilt_slide_vs_belt: 0.000000 mm3
- pan_tower_vs_motor: 0.000000 mm3
- pan_adapter_vs_belt: 0.000000 mm3
- camera_vs_tilt_motor_nominal: 0.000000 mm3
- camera_plate_vs_tilt_motor_nominal: 0.000000 mm3

## Tilt pose checks
- Tilt -60 deg: 0.000000 mm3
- Tilt 0 deg: 0.000000 mm3
- Tilt 60 deg: 0.000000 mm3

## Result
- Valid B-reps: True
- Geometry validation passed: True

## Production limitations
- Replace visual pulley teeth with an exact vendor GT2 profile.
- Confirm the selected turntable bearing and closed-loop belt dimensions.
- Measure the physical HC-V760 including battery, LCD travel, lens, and connectors.
- Add final screw threads, inserts, tolerances, fillets, and print-orientation details.

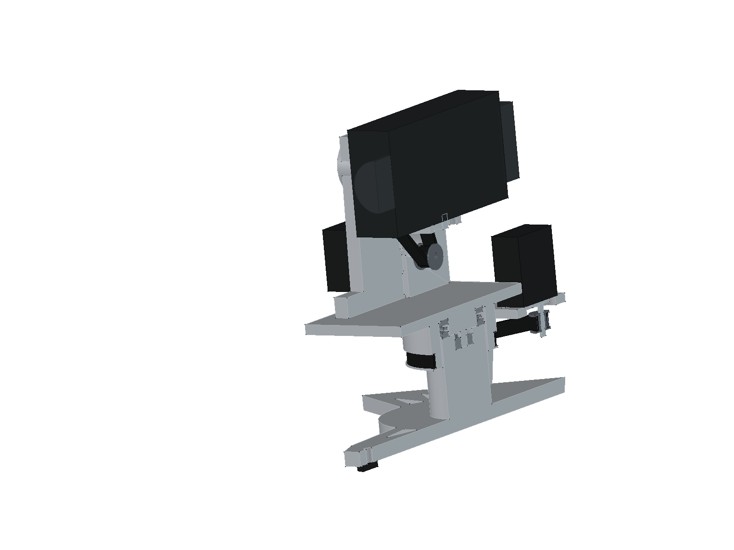
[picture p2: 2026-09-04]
screenshots/section_xz_through_pan_axis_v8.png

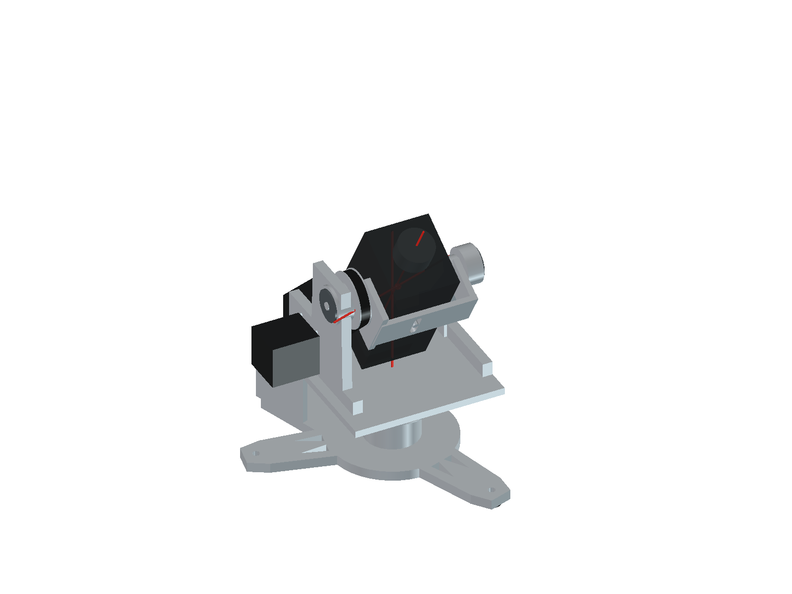
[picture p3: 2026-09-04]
screenshots/09_tilt_minus60_v8.png

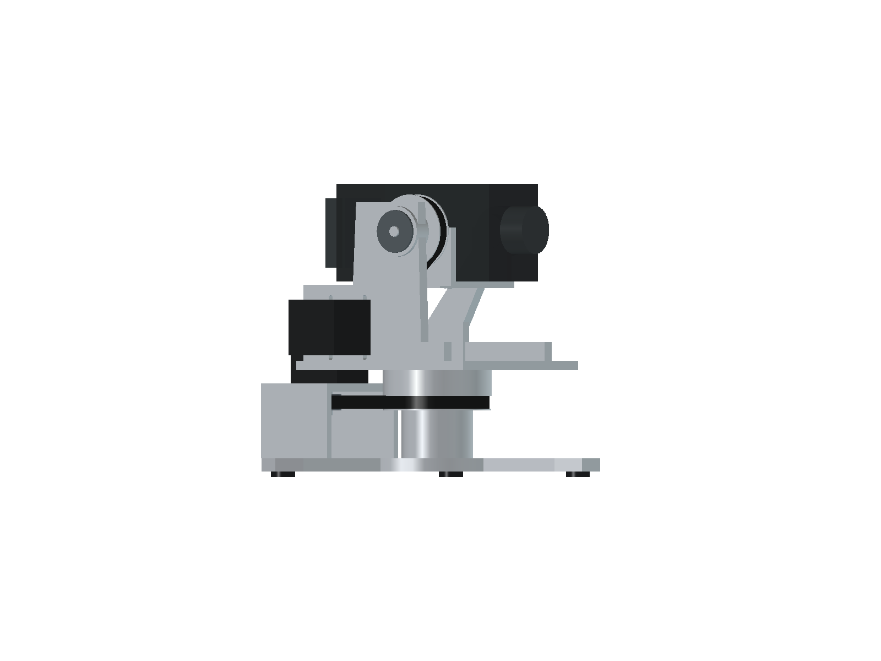
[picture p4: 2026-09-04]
screenshots/03_side_v8.png

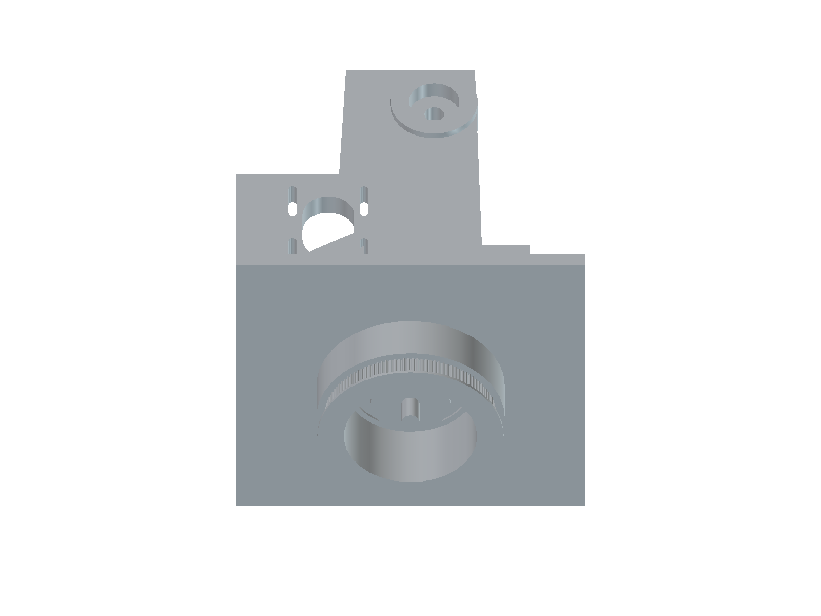
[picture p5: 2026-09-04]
screenshots/18_integral_pan_120T_bottom_v8.png

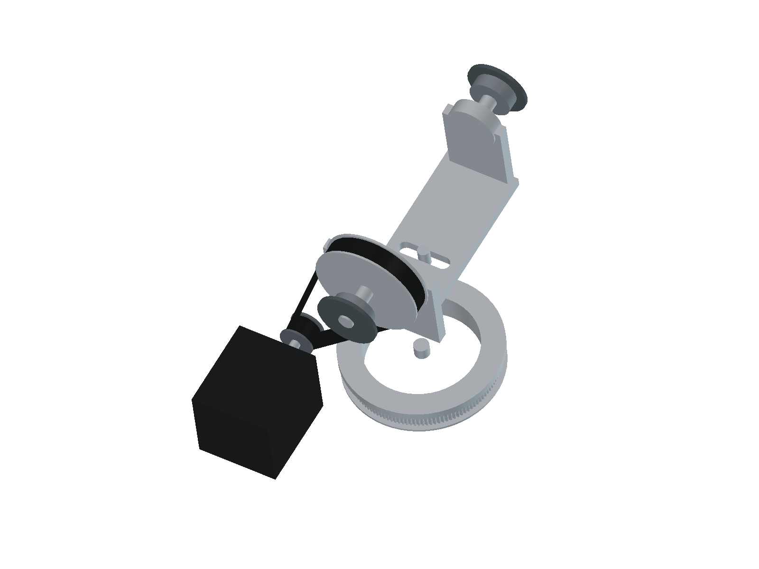
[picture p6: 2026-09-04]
screenshots/07_tilt_drive_focus_v8.png

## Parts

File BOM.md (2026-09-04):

# BOM V8

## Printed concept parts
- 1x three-leg lower base with integral 51107/608 seats and downward-shaft pan motor mount
- 1x one-piece pan rotating solid: 152 mm square-topped platform with both pan yokes (LCD-clearance rear-routed left support, direct-NEMA17 right support), both gussets, plastic journal, thrust hub, connector skirt, and real 120T GT2/2MR pulley — one printed part
- 2x 608 bearing caps
- 1x one-piece printed tilt cradle with a 39x98 mm camera saddle, both cheeks, two 7.9 mm trunnions, and integral inboard 80T GT2/2MR pulley with a 10 mm face

## Bought components
- 1x NEMA17 stepper motor for pan
- 1x StepperOnline 17HS19-2004S1 NEMA17 for tilt, 42x42x48 mm with a 5x24 mm shaft
- 1x 51107 / 8107 thrust bearing, 35x52x12 mm
- 3x 608-2RS bearing, 8x22x7 mm: two tilt and one pan radial bearing
- 1x GT2 20T metal pulley for pan; the 120T driven pulley is integral to the printed pan platform
- 1x GT2 20T metal pulley for tilt; the 80T driven pulley is integral to the printed cradle
- 1x GT2 10 mm belt, approximately 350 mm for pan; confirm after setting motor position
- 1x GT2 10 mm belt, nominal 280 mm for tilt
- 1x 1/4-20 camera screw
- M3 motor screws, M4 bearing-cap screws, M5 base fasteners
- 3x rubber feet

## Ratios
- Pan: 120T / 20T = 6.0:1
- Tilt: 80T / 20T = 4.0:1

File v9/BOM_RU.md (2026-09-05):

# Комплектующие V9

## Покупные детали

| Деталь | Количество | Размер / примечание |
|---|---:|---|
| NEMA17 | 2 | 42×42×48 мм, вал 5×24 мм; геометрия StepperOnline 17HS19-2004S1 |
| 608-2RS | 3 | 8×22×7 мм |
| 51107 / 8107 | 1 | 35×52×12 мм, полный комплект шайб и сепаратора |
| Металлический шкив GT2 20T | 2 | Под ремень 10 мм и вал 5 мм; ступица не более Ø16 в принятом габарите |
| Замкнутый ремень GT2 | 1 | 350 мм, ширина 10 мм (175 зубьев) |
| Замкнутый ремень GT2 | 1 | 280 мм, ширина 10 мм (140 зубьев) |
| Гайка M3 | 42 | Обычная, под ключ 5,5 мм, толщина около 2,4 мм |
| Винт камеры 1/4–20 | 1 | Длину подбирать по выступанию через площадку 8 мм и глубине гнезда камеры |
| Нескользящие ножки | 3–4 | По желанию; при наклейке одинаковой толщины обеспечить контакт опоры мотора |

## Винты M3 DIN 912

Длина указана от опорной поверхности головки. Головка цилиндрическая, шестигранник 2,5 мм; гайки вплавлять не нужно. Количество без запаса.

| Размер | Количество |
|---|---:|
| M3×6 | 4 |
| M3×10 | 21 |
| M3×12 | 8 |
| M3×16 | 14 |
| M3×20 | 1 |
| M3×25 | 1 |
| M3×35 | 1 |

Всего 50 винтов M3, из них 8 входят в резьбу моторов, остальные 42 — в гайки. Штатные стопорные винты малых шкивов и крепёж к столу в это число не входят.

## Печатные детали

Каждый файл STL — одна деталь, печатать по одному экземпляру. Три ноги и обе симметричные крышки уже представлены отдельными файлами.

| Код детали | Объём CAD, см³ |
|---|---:|
| B01_Central_pedestal | 227.5 |
| B02_Leg_1 | 18.1 |
| B02_Leg_2 | 18.1 |
| B02_Leg_3 | 18.1 |
| B04_Motor_stand_-1 | 21.0 |
| B04_Motor_stand_1 | 21.0 |
| B03_Motor_stand_foot | 48.3 |
| B05_Pan_motor_deck | 25.7 |
| B06_Pan_608_retainer | 7.4 |
| P01_Pan_rotor_120T | 65.4 |
| P02_Pan_axial_retainer | 0.2 |
| P04_Yoke_left | 76.8 |
| P05_608_cap_1 | 5.1 |
| P04_Yoke_right | 122.1 |
| P05_608_cap_-1 | 5.1 |
| P03_Pan_platform | 228.6 |
| T02_Cheek_left | 11.5 |
| T03_Axial_retainer_1 | 0.2 |
| T02_Cheek_right_80T | 42.9 |
| T03_Axial_retainer_-1 | 0.2 |
| T01_Camera_saddle | 30.9 |

Объём CAD — объём сплошного тела; расход филамента определит слайсер по заполнению и стенкам. Калибровочный образец CAL_Fit_coupon в сборку не входит.

## Крепёж по узлам

| Идентификатор в FreeCAD | Винт | Гайка |
|---|---|---|
| H_Pan608_cap_0 | M3×10 | M3 |
| H_Pan608_cap_1 | M3×10 | M3 |
| H_Pan608_cap_2 | M3×10 | M3 |
| H_Leg_0_0 | M3×10 | M3 |
| H_Leg_0_1 | M3×10 | M3 |
| H_Leg_1_0 | M3×10 | M3 |
| H_Leg_1_1 | M3×10 | M3 |
| H_Leg_2_0 | M3×10 | M3 |
| H_Leg_2_1 | M3×10 | M3 |
| H_Motor_foot_-12 | M3×10 | M3 |
| H_Motor_foot_12 | M3×10 | M3 |
| H_Stand_bottom_-1_0 | M3×16 | M3 |
| H_Stand_top_-1_0 | M3×12 | M3 |
| H_Stand_bottom_-1_1 | M3×16 | M3 |
| H_Stand_top_-1_1 | M3×12 | M3 |
| H_Stand_bottom_1_0 | M3×16 | M3 |
| H_Stand_top_1_0 | M3×12 | M3 |
| H_Stand_bottom_1_1 | M3×16 | M3 |
| H_Stand_top_1_1 | M3×12 | M3 |
| H_Pan_motor_0_0 | M3×6 | Резьба двигателя |
| H_Pan_motor_0_1 | M3×6 | Резьба двигателя |
| H_Pan_motor_1_0 | M3×6 | Резьба двигателя |
| H_Pan_motor_1_1 | M3×6 | Резьба двигателя |
| H_Rotor_platform_0 | M3×10 | M3 |
| H_Rotor_platform_1 | M3×10 | M3 |
| H_Rotor_platform_2 | M3×10 | M3 |
| H_Rotor_platform_3 | M3×10 | M3 |
| H_Pan_axial | M3×20 | M3 |
| H_Yoke_base_1_0 | M3×16 | M3 |
| H_Yoke_base_1_1 | M3×16 | M3 |
| H_Yoke_base_1_2 | M3×16 | M3 |
| H_Tilt608_cap_1_0 | M3×10 | M3 |
| H_Tilt608_cap_1_1 | M3×10 | M3 |
| H_Tilt608_cap_1_2 | M3×10 | M3 |
| H_Yoke_base_-1_0 | M3×16 | M3 |
| H_Yoke_base_-1_1 | M3×16 | M3 |
| H_Yoke_base_-1_2 | M3×16 | M3 |
| H_Tilt_motor_0_0 | M3×12 | Резьба двигателя |
| H_Tilt_motor_0_1 | M3×12 | Резьба двигателя |
| H_Tilt_motor_1_0 | M3×12 | Резьба двигателя |
| H_Tilt_motor_1_1 | M3×12 | Резьба двигателя |
| H_Tilt608_cap_-1_0 | M3×10 | M3 |
| H_Tilt608_cap_-1_1 | M3×10 | M3 |
| H_Tilt608_cap_-1_2 | M3×10 | M3 |
| H_Cradle_foot_1_0 | M3×16 | M3 |
| H_Cradle_foot_1_1 | M3×16 | M3 |
| H_Tilt_axial_1 | M3×25 | M3 |
| H_Cradle_foot_-1_0 | M3×16 | M3 |
| H_Cradle_foot_-1_1 | M3×16 | M3 |
| H_Tilt_axial_-1 | M3×35 | M3 |

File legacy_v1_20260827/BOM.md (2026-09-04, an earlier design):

# BOM

## Printed parts
- 1x Base: four-leg printed base, central pan bearing housing area
- 1x Pan motor mount: slotted +/-5 mm tension adjustment for NEMA17
- 1x Pan output hub: bearing-supported rotating hub, cable bore through center
- 1x Pan driven pulley: integrated printed GT2-10, 80T
- 1x Rotating upper plate: carries tilt frame and tilt motor
- 1x Left tilt support: 608 bearing pocket with printed retainer geometry
- 1x Right tilt support: 608 bearing pocket plus tilt motor bracket
- 1x Tilt motor bracket: slotted NEMA17 mount, vertical belt adjustment
- 1x Tilt driven pulley: printed GT2-10, 80T, bolted to camera cradle/axle hub
- 1x Tilt camera cradle / camera plate: 160x80x5 plate, 1/4-20 longitudinal slot
- 1x Cable guides / tie slots: slots on camera plate and center cable passage

## Bought components
- 2x NEMA17 stepper motor: 42 mm frame, 31 mm hole spacing
- 2x GT2 20T metal motor pulley, 5 mm bore, 10 mm belt: one per motor
- 2x GT2 belt, 10 mm width: closed-loop length selected after final center distance
- 4x 608ZZ bearing 8x22x7: two for pan, two for tilt
- 2x 8 mm metal shaft / shoulder bolt: pan fixed shaft and tilt axle
- 8x M3 screws: NEMA17 mounting
- 8x M5 screws / washers / nuts: base, yoke, retainers, camera plate accessories
- 1x 1/4-20 UNC camera screw: camera mounting slot
- 4x Rubber feet: base legs
- 1x Panasonic HC-V760 placeholder: 65x73x139 envelope, design load 0.6 kg

## Drive ratios
- Pan: 80T / 20T = 4.0:1
- Tilt: 80T / 20T = 4.0:1

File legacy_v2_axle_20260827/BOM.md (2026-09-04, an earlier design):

# BOM V2

## Printed concept parts
- 1x three-leg base with motor bay and gusseted feet
- 1x pan motor radial slide plate
- 1x pan bearing adapter and 120T driven ring
- 1x rotating pan platform with 55 mm cable bore
- 1x compact two-sided yoke with integrated tilt motor mount
- 2x 608 bearing caps
- 1x balanced camera cradle and camera plate

## Bought components
- 2x NEMA17 stepper motor, 42 mm frame
- 1x 110x86x12 mm precision turntable bearing
- 2x 608-2RS bearing, 8x22x7 mm
- 1x 8 mm steel tilt axle, 144 mm long
- 1x GT2 20T metal pulley and 1x 120T driven pulley for pan
- 1x GT2 20T metal pulley and 1x 80T driven pulley for tilt
- 1x GT2 10 mm belt, nominal 252 mm for pan
- 1x GT2 10 mm belt, nominal 280 mm for tilt
- 1x 1/4-20 camera screw
- M3 motor screws, M4 bearing-cap screws, M5 base fasteners
- 3x rubber feet

## Ratios
- Pan: 120T / 20T = 6.0:1
- Tilt: 80T / 20T = 4.0:1

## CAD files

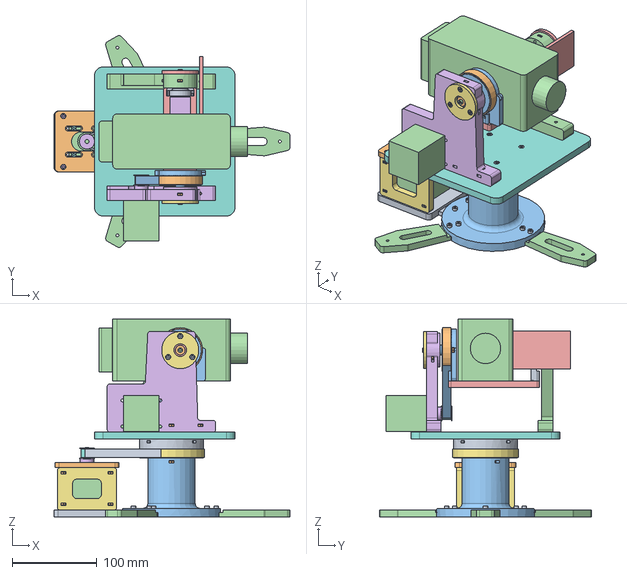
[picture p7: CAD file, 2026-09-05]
v9/output/PanTilt_V9_assembly.step
278.9 x 250.4 x 233.5 mm

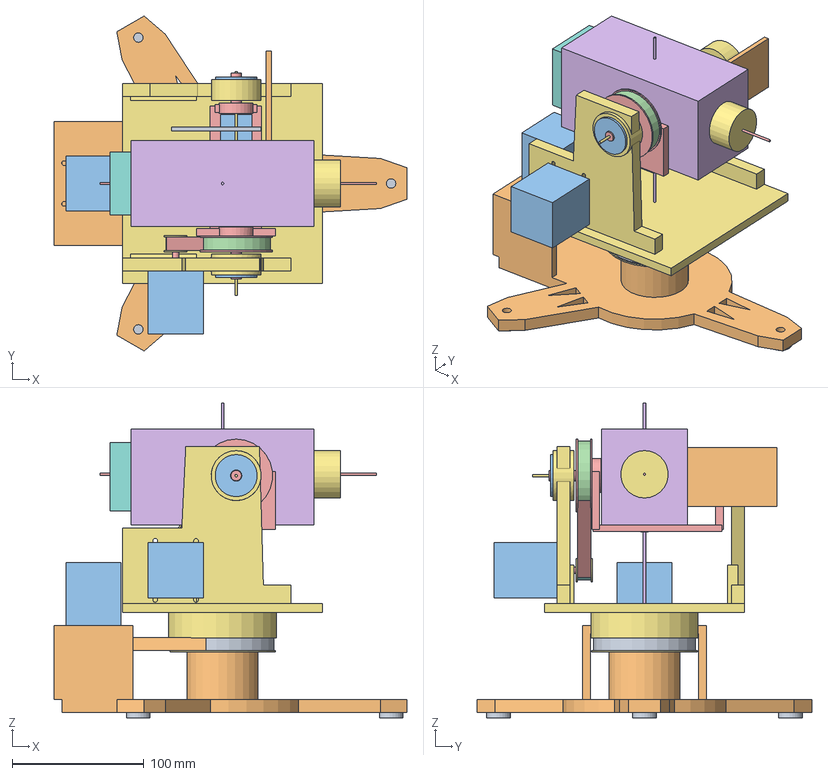
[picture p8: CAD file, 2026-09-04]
pantilt_hc_v760_nema17_gt2.step
268.0 x 254.5 x 239.0 mm
BASE_rubber_foot_0 x 3
BASE_rubber_foot_120 x 3
BASE_rubber_foot_240 x 3
BASE_three_leg_frame_51107_608_motor_mount x 3
BASE_pan_motor_NEMA17 x 3
BASE_pan_motor_pilot x 3
BASE_pan_motor_shaft x 3
BASE_pan_motor_20T_pulley x 3
BASE_pan_motor_20T_flanges x 3
BASE_pan_608_radial_bearing_press_fit x 3
BASE_pan_51107_lower_housing_washer x 3
BASE_pan_51107_ball_cage x 3
BASE_pan_51107_upper_shaft_washer x 3
TILT_ROTATING_one_piece_cradle_trunnions_80T x 4
CAMERA_HC_V760_body_placeholder x 4
CAMERA_HC_V760_lens x 4
CAMERA_HC_V760_rear_battery x 4
CAMERA_flip_screen_clearance_closed x 4
CAMERA_flip_screen_clearance_open x 4
CAMERA_HDMI_cable_clearance_20mm x 4
CAMERA_nominal_COG x 4
CAMERA_optical_axis x 4
TILT_ROTATING_camera_mount_screw x 4
PAN_ROTATING_one_piece_platform_journal_120T_GT2 x 3
BASE_pan_GT2_350mm_belt x 3
PAN_ROTATING_left_608_bearing x 3
PAN_ROTATING_right_608_bearing x 3
PAN_ROTATING_left_bearing_cap x 3
PAN_ROTATING_right_bearing_cap x 3
PAN_ROTATING_tilt_motor_NEMA17 x 3
PAN_ROTATING_tilt_motor_pilot x 3
PAN_ROTATING_tilt_motor_shaft x 3
PAN_ROTATING_tilt_motor_20T_pulley x 3
PAN_ROTATING_tilt_motor_20T_flanges x 3
PAN_ROTATING_tilt_GT2_280mm_belt x 3
REFERENCE_pan_axis x 2
REFERENCE_tilt_axis x 2
X-axis x 15
XY-plane x 15

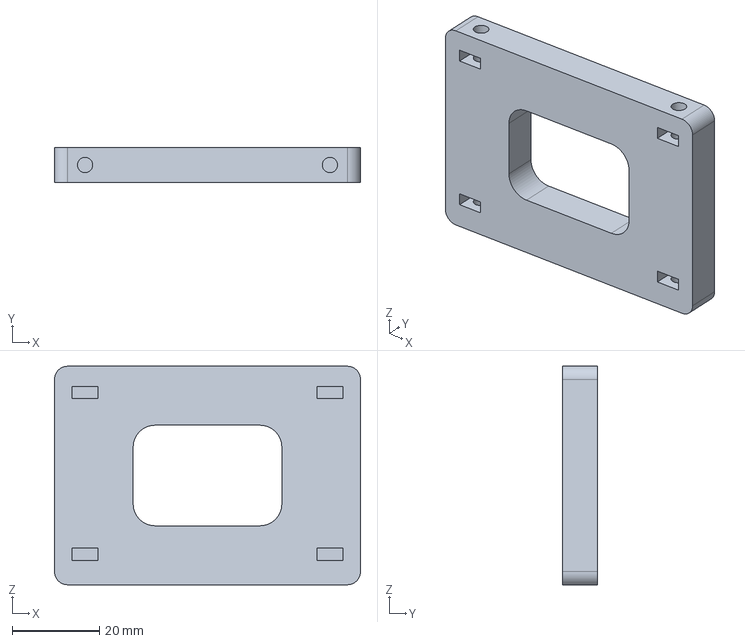
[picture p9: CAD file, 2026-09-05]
v9/output/step/B04_Motor_stand_-1.step
70.0 x 8.00 x 50.0 mm

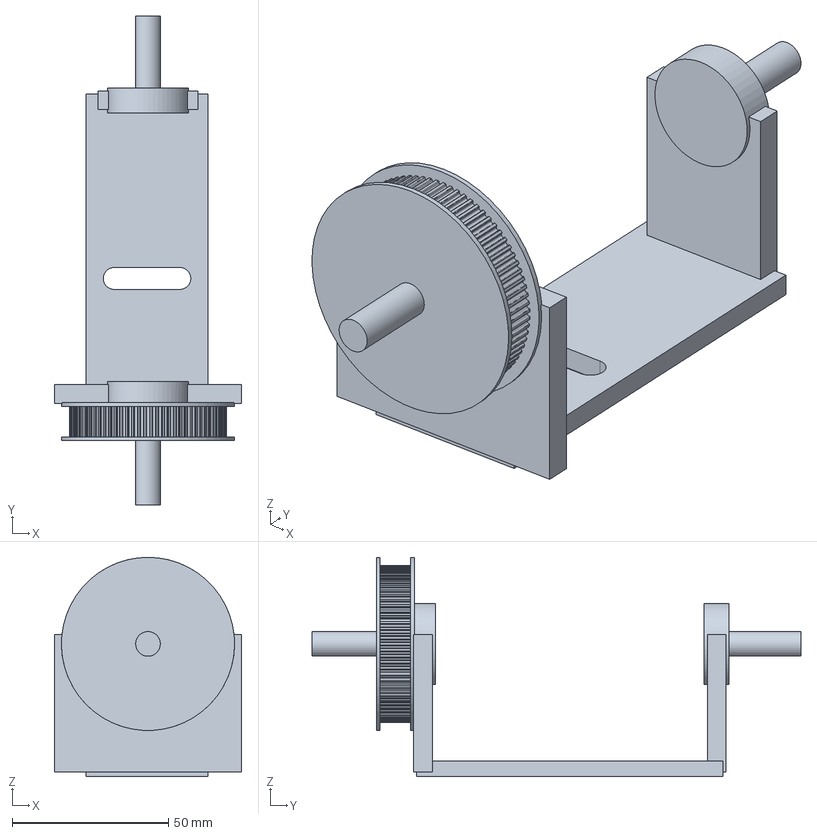
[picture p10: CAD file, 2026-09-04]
tilt_cradle_integral_gt2_80T.step
60.0 x 156.5 x 70.2 mm

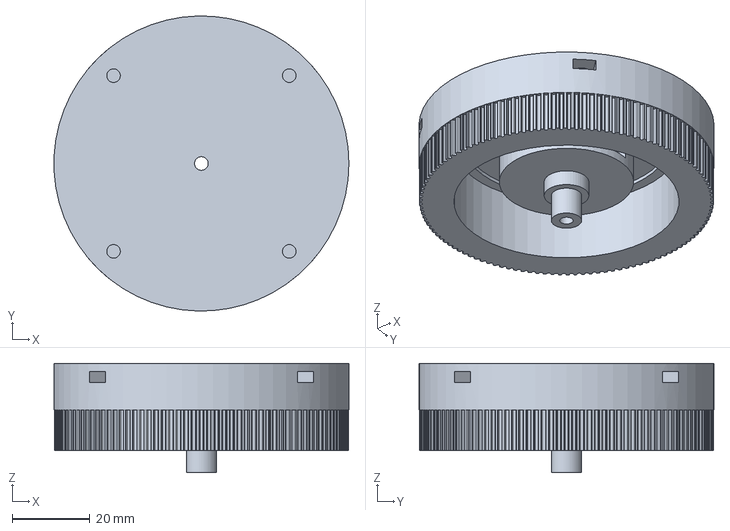
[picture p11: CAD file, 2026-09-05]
v9/output/step/P01_Pan_rotor_120T.step
75.9 x 76.0 x 28.2 mm

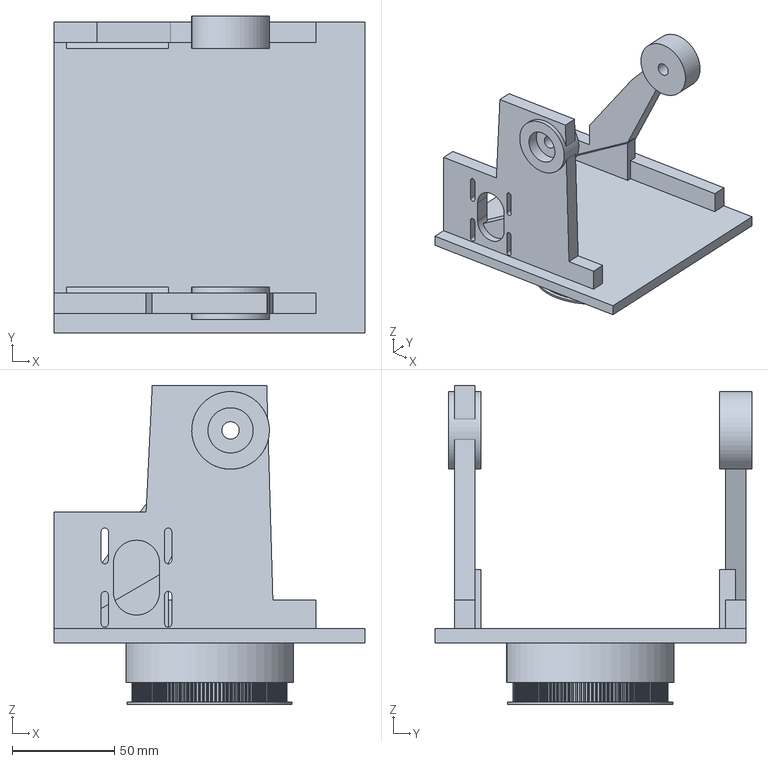
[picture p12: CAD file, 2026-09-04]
pan_one_piece_square_platform_yokes_120T_GT2.step
152.0 x 155.0 x 156.1 mm

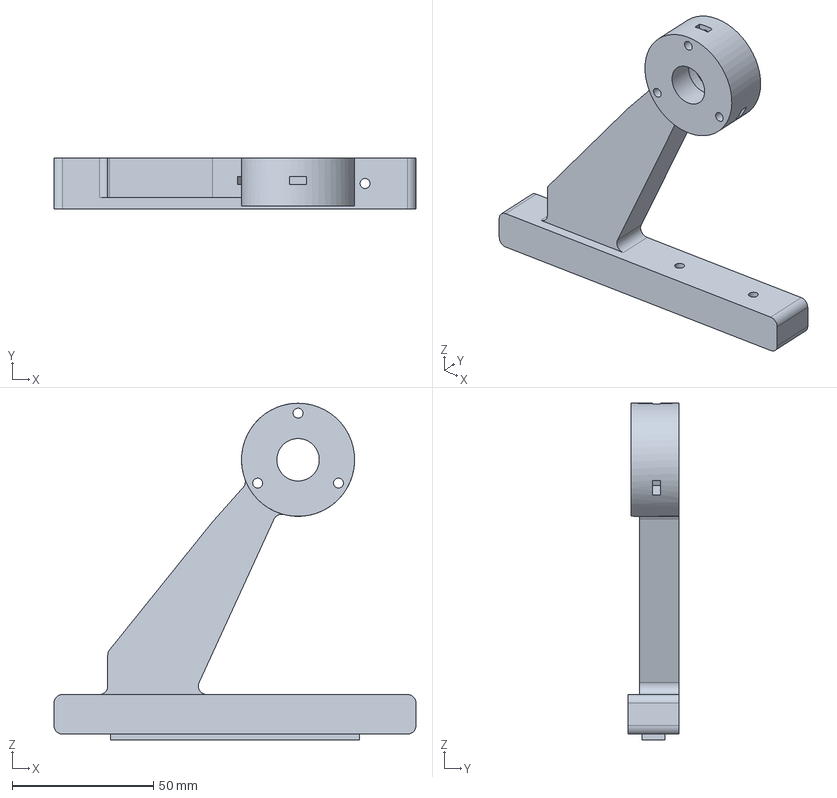
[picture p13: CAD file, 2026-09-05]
v9/output/step/P04_Yoke_left.step
128.0 x 18.0 x 119.0 mm

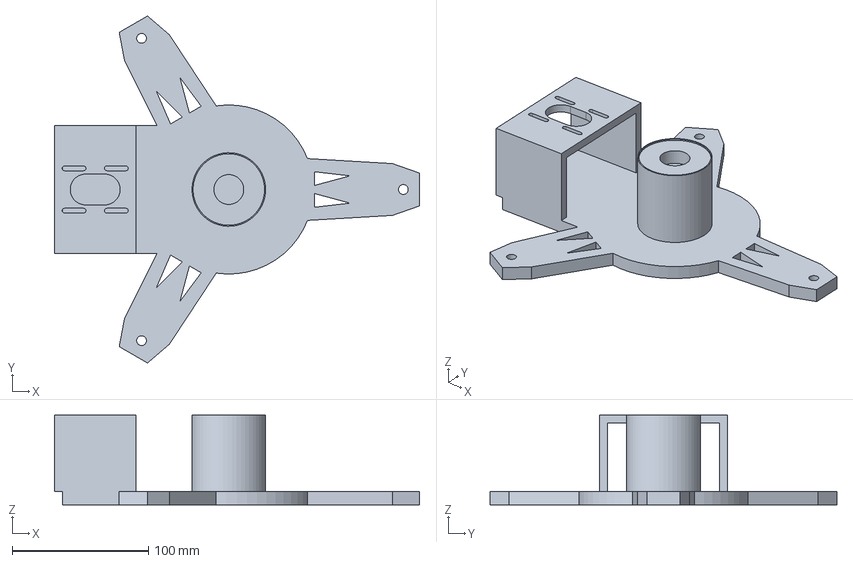
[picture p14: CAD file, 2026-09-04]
base_51107_608_downshaft_nema17.step
268.0 x 254.5 x 66.0 mm

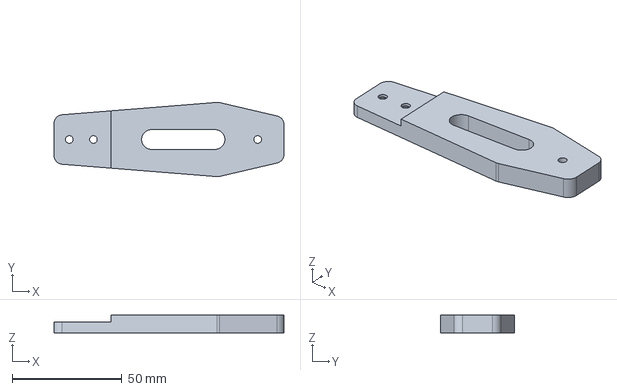
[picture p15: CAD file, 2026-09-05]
v9/output/step/B02_Leg_1.step
105.0 x 33.9 x 8.00 mm

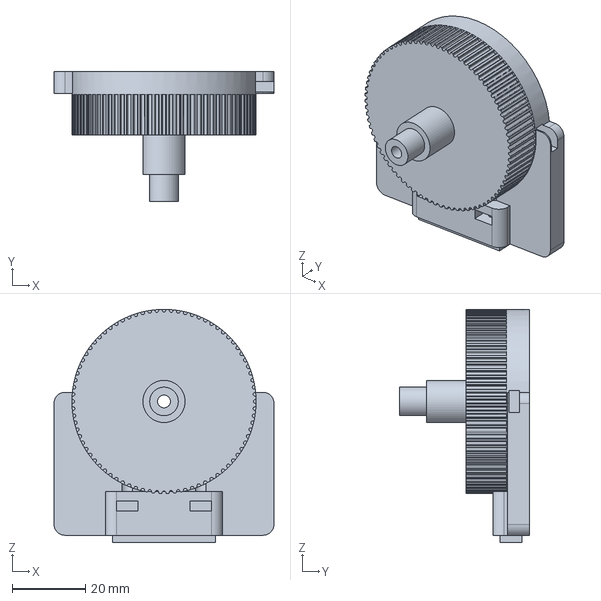
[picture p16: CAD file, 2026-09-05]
v9/output/step/T02_Cheek_right_80T.step
60.0 x 35.5 x 63.6 mm

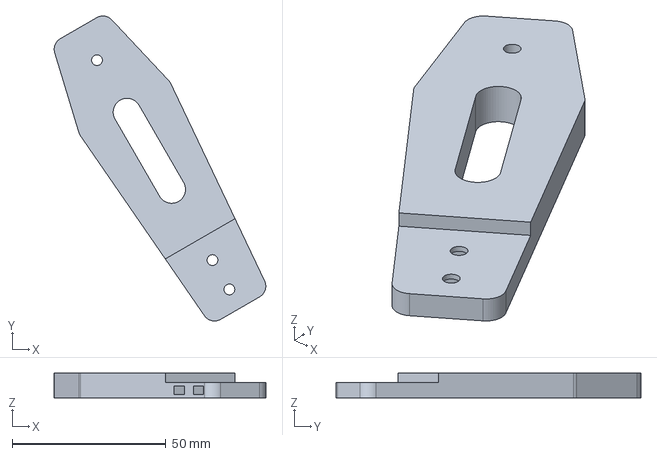
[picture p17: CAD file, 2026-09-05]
v9/output/step/B02_Leg_2.step
68.7 x 99.1 x 8.00 mm

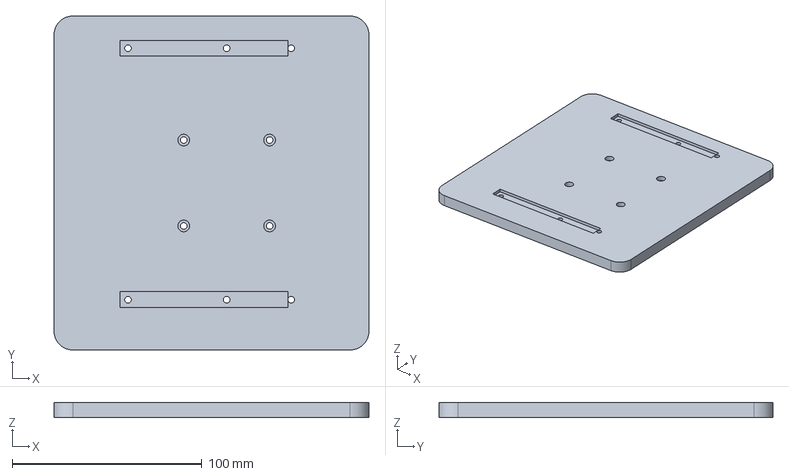
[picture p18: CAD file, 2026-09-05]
v9/output/step/P03_Pan_platform.step
166.0 x 176.0 x 8.00 mm

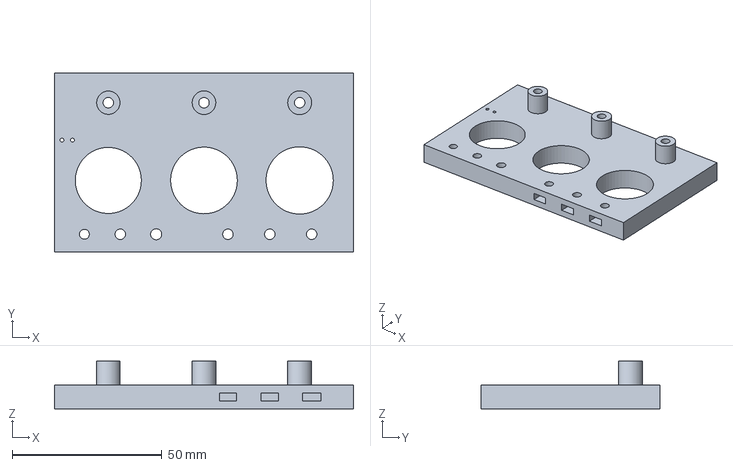
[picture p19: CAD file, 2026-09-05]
v9/output/step/CAL_Fit_coupon.step
100.0 x 60.0 x 16.0 mm

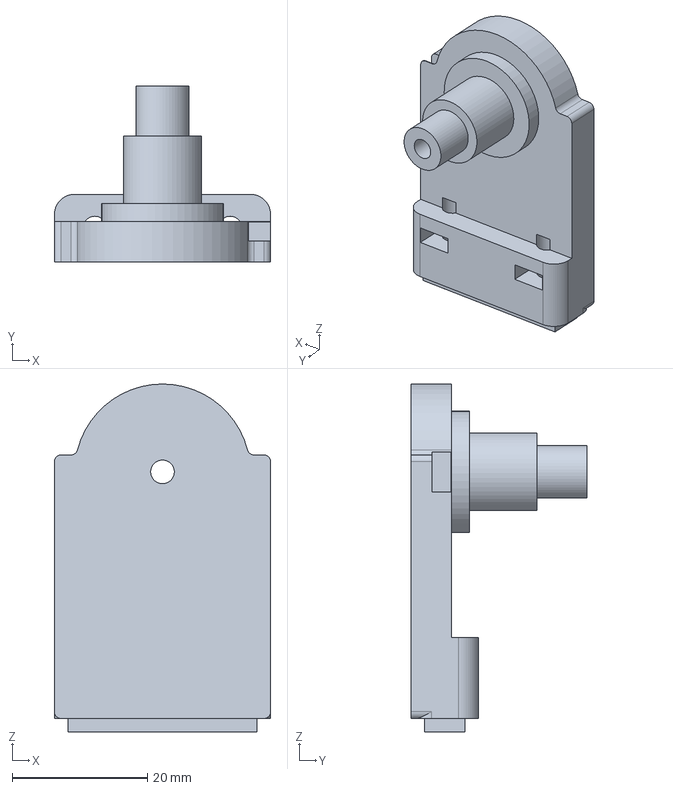
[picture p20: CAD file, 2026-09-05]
v9/output/step/T02_Cheek_left.step
32.0 x 26.0 x 51.5 mm

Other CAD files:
v9/output/PanTilt_V9_HC-V760.FCStd
v9/output/step/B06_Pan_608_retainer.step
v9/output/step/T03_Axial_retainer_-1.step
v9/output/step/B01_Central_pedestal.step
base_51107_608_downshaft_nema17.stl
legacy_v1_20260827/pantilt_hc_v760_nema17_gt2.FCStd
legacy_v1_20260827/pantilt_hc_v760_nema17_gt2.step
legacy_v2_axle_20260827/pantilt_hc_v760_nema17_gt2.FCStd
legacy_v2_axle_20260827/pantilt_hc_v760_nema17_gt2.step
legacy_v3_outboard_pulley_20260827/pantilt_hc_v760_nema17_gt2.FCStd
legacy_v3_outboard_pulley_20260827/pantilt_hc_v760_nema17_gt2.step
legacy_v4_visual_gt2_20260827/pantilt_hc_v760_nema17_gt2.FCStd
legacy_v4_visual_gt2_20260827/pantilt_hc_v760_nema17_gt2.step
legacy_v5_printable_gt2_20260827/pantilt_hc_v760_nema17_gt2.FCStd
legacy_v5_printable_gt2_20260827/pantilt_hc_v760_nema17_gt2.step
legacy_v5_printable_gt2_20260827/tilt_cradle_integral_gt2_80T.step
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

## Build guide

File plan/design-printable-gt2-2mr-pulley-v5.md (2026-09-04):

---
goal: Printable GT2 2MR Integral Tilt Pulley V5
version: 5.0
date_created: 2026-08-27
last_updated: 2026-08-27
owner: Codex
status: 'Completed'
tags: [design, freecad, mechanical, gt2, fdm]
---

# Introduction



Replace the decorative rectangular teeth on the integral 80T tilt pulley with a continuous printable GT2/2MR groove profile. Preserve the accepted v4 architecture, expose FDM fit compensation, and export the complete one-piece tilt cradle as standalone STEP and STL files.

## 1. Requirements & Constraints

- **REQ-001**: Generate the 80T driven pulley from a closed 2 mm pitch modified-curvilinear GT2/2MR profile, not discrete rectangular boxes.
- **REQ-002**: Keep the pulley face width at 10 mm and the tilt ratio at 20T/80T = 4:1.
- **REQ-003**: Keep camera plate, cheeks, hubs, trunnions, and driven pulley in one `Part::Feature` containing one connected solid.
- **REQ-004**: Expose radial and tangential FDM compensation parameters without changing tooth count or pitch diameter.
- **REQ-005**: Validate profile closure, profile face validity, tooth count, pitch diameter, outside diameter, and generated arc count.
- **REQ-006**: Preserve the no-through-shaft architecture, inboard pulley order, bearing/yoke clearances, and -60/0/+60 degree collision-free tilt range.
- **REQ-007**: Export the full assembly plus standalone printable tilt-cradle STEP and STL artifacts.
- **REQ-008**: Render v5 assembly views, a pulley profile close-up, and a new reference comparison sheet.
- **CON-001**: Leave the provisional pan mechanism and its visual 120T tooth representation unchanged.
- **CON-002**: Preserve v4 under `/home/user/pantilt/legacy_v4_visual_gt2_20260827/`.
- **GUD-001**: Use the existing deterministic FreeCAD 1.1.3 Python workflow.

## 2. Implementation Steps

### Implementation Phase 1

- GOAL-001: Build the functional 2MR geometry.

| Task | Description | Completed | Date |
|---|---|---|---|
| TASK-001 | Back up the complete v4 source, model, reports, plan, and screenshots. | yes | 2026-08-27 |
| TASK-002 | Implement the 2MR groove outline from circular arcs and connecting land segments. | yes | 2026-08-27 |
| TASK-003 | Add explicit radial and tangential print-fit compensation parameters. | yes | 2026-08-27 |
| TASK-004 | Fuse the profiled 80T body and flanges into the existing one-piece tilt cradle. | yes | 2026-08-27 |

### Implementation Phase 2

- GOAL-002: Validate and deliver print artifacts.

| Task | Description | Completed | Date |
|---|---|---|---|
| TASK-005 | Add profile topology and dimensional acceptance checks to `geometry_validation.json`. | yes | 2026-08-27 |
| TASK-006 | Export assembly FCStd/STEP and standalone tilt cradle STEP/STL. | yes | 2026-08-27 |
| TASK-007 | Re-run B-rep, one-solid, clearance, and tilt-pose interference checks. | yes | 2026-08-27 |
| TASK-008 | Render and visually inspect v5 views and the profile close-up. | yes | 2026-08-27 |
| TASK-009 | Update README, BOM, CAD checks, and mark this plan complete. | yes | 2026-08-27 |

## 3. Alternatives

- **ALT-001**: Rectangular radial teeth were rejected because they do not mate with the modified-curvilinear GT2 belt tooth.
- **ALT-002**: Importing a vendor mesh was rejected because it would remove deterministic parametric control and complicate fusion into the cradle.
- **ALT-003**: Claiming a universal zero-clearance profile was rejected because FDM shrinkage, extrusion width, and actual belt tolerances require printer-specific calibration.

## 4. Dependencies

- **DEP-001**: `/home/user/pantilt/squashfs-root/usr/bin/freecadcmd` from FreeCAD 1.1.3.
- **DEP-002**: `/home/user/Applications/FreeCAD-1.1.3.AppImage` for GUI screenshot rendering.
- **DEP-003**: Gates 2MR dimensions and the FreeCAD TimingGear GT2 arc construction.
- **DEP-004**: Local FFmpeg for the reference comparison sheet.

## 5. Files

- **FILE-001**: `/home/user/pantilt/build_pantilt_freecad.py` - v5 profile, assembly, validation, and export generator.
- **FILE-002**: `/home/user/pantilt/make_screenshots_freecad.py` - v5 rendering and comparison generator.
- **FILE-003**: `/home/user/pantilt/geometry_validation.json` - machine-readable profile and assembly checks.
- **FILE-004**: `/home/user/pantilt/tilt_cradle_integral_gt2_80T.step` - standalone editable tilt part.
- **FILE-005**: `/home/user/pantilt/tilt_cradle_integral_gt2_80T.stl` - standalone printable tilt part.
- **FILE-006**: `/home/user/pantilt/README.md` - manufacturing scope and calibration guidance.

## 6. Testing

- **TEST-001**: Run `/home/user/pantilt/generate_pantilt_freecad.sh` and require exit code 0.
- **TEST-002**: Require a closed, valid 80T profile with 400 circular arcs and 80 land segments.
- **TEST-003**: Require the integral tilt feature and solid counts to equal one and all generated B-reps to be valid.
- **TEST-004**: Require every selected static and -60/0/+60 degree pose intersection to be at most 0.01 mm3.
- **TEST-005**: Require standalone STEP/STL outputs to exist and the STL to contain a nonzero mesh.
- **TEST-006**: Require non-empty 1600x1200 v5 screenshots plus original-resolution visual inspection of the pulley close-up and reference comparison.

## 7. Risks & Assumptions

- **RISK-001**: The starting print compensation is geometrically explicit but must still be calibrated with the actual belt, material, nozzle, slicer, and printer.
- **RISK-002**: Fine 2 mm pitch features may print poorly with coarse nozzles or unfavorable part orientation.
- **RISK-003**: Printed trunnion wear, creep, and layer adhesion remain physical-test concerns.
- **ASSUMPTION-001**: The belt is a 2 mm pitch GT2/2MR-compatible belt with a nominal 10 mm width.
- **ASSUMPTION-002**: The user wants the integrated tilt pulley upgraded now; the pan ring remains provisional for later review.

## 8. Related Specifications / Further Reading

`/home/user/pantilt/plan/design-inboard-tilt-pulley-v4.md`

`https://www.gates.com/content/dam/documents-library/catalogs/power-transmission-catalog.pdf`

`https://reqrefusion.github.io/FreeCAD-Documentation-html/wiki/Macro_TimingGear.html`
